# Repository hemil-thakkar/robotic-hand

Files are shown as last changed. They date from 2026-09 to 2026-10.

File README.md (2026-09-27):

# robotic-hand
# Tendon-driven robotic hand

Building a tendon-driven robotic hand as a step toward prosthetics and
wearable robotics research. Based on the open-source
[InMoov](https://inmoov.fr) hand, with my own modifications.

Biomedical engineering, Georgia Tech.

## Goals

- [ ] Print and assemble a single working finger
- [ ] Drive the finger with a servo and Arduino
- [ ] Build the full hand and forearm
- [ ] Design my own parts (mount, electrode holder, modified joint)
- [ ] Compare my finger design against the original for grip and range of motion
- [ ] Control the hand with an EMG (muscle) signal

## Status

**Stage 0 — first finger.** Repo set up. Next: print the InMoov finger
parts at the Georgia Tech Invention Studio, then assemble and string
the tendon.

See [`docs/build-log.md`](docs/build-log.md) for session notes.

## Repo layout

| Folder | Contents |
|---|---|
| `cad/` | My Fusion designs and exported STL files |
| `cad/reference/` | InMoov STL files as printed (not my designs) |
| `code/` | Arduino sketches and analysis scripts |
| `docs/` | Build log and test results |
| `docs/photos/` | Build photos, named by date |
| `data/` | Measurements from tests |

## Built with

- 3D printing at the Georgia Tech Invention Studio
- Autodesk Fusion for CAD
- Arduino for servo control

## Credit

Mechanical design based on the InMoov open-source humanoid robot by
Gael Langevin, licensed CC-BY-NC. Files in `cad/reference/` are his.
My own parts and code are in `cad/`, `code/`, and noted as mine in the
build log.

Mechanical design based on the InMoov open-source humanoid robot by
Gael Langevin, licensed CC-BY-NC. Files in `cad/reference/` are his.
My own parts and code are in `cad/`, `code/`, and noted as mine in the
build log.

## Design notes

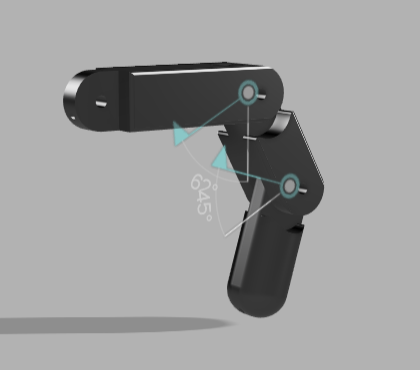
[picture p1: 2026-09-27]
photos/fusion-render-v1-finger.png

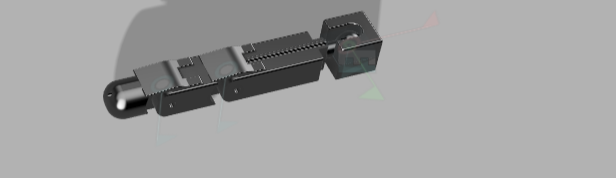
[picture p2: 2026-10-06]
photos/full-finger-v2.png

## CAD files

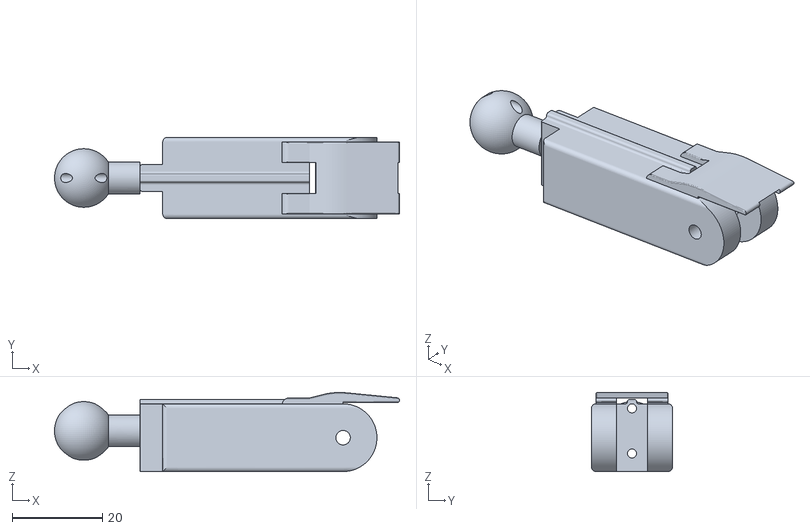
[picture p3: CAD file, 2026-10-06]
cad/personal cads/sweeps version/segment-proximal-ball-v1.stl
76.5 x 18.0 x 17.5

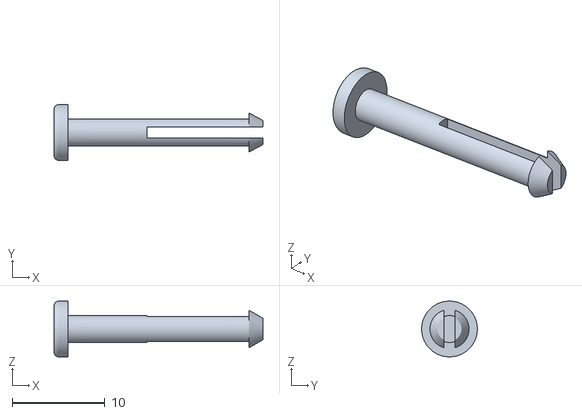
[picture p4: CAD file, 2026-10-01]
cad/personal cads/v1 (9-27-26)/connection-pin-v1.stl
22.5 x 6.00 x 6.00

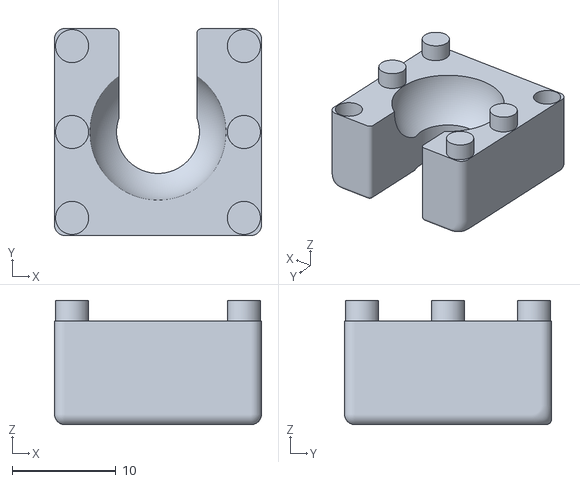
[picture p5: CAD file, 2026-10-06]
cad/personal cads/v2 (10-6-26)/socket-cap-v2.stl
20.0 x 20.0 x 12.0

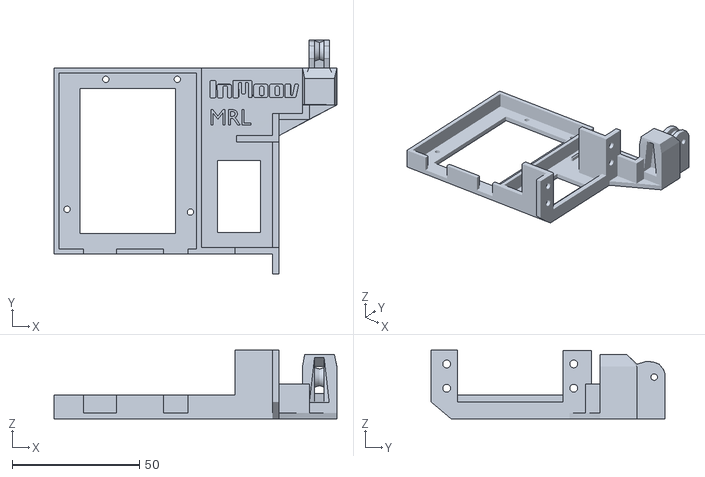
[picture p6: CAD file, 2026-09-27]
cad/reference/FingerTesterV2.stl
111.0 x 91.8 x 26.9

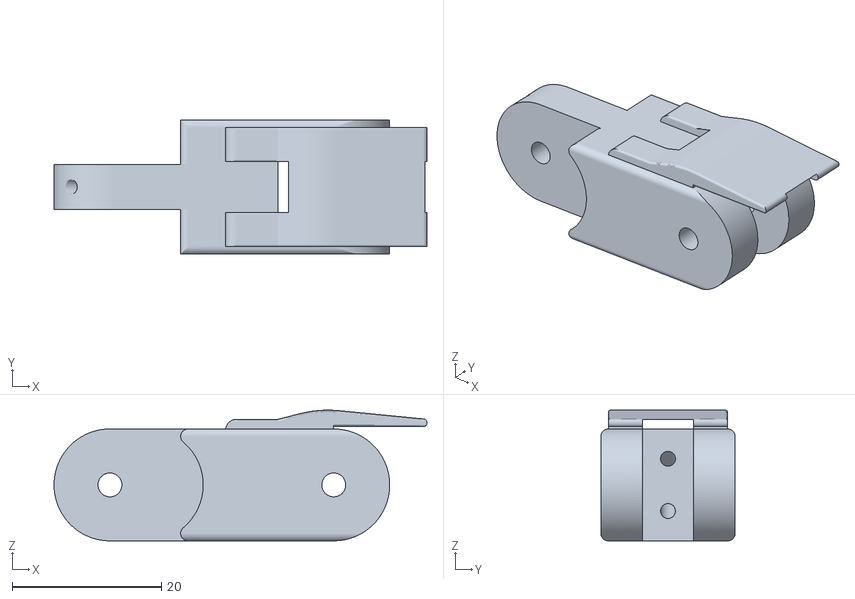
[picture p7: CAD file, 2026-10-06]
cad/personal cads/sweeps version/segment-middle-vSweep.stl
50.0 x 18.0 x 17.5

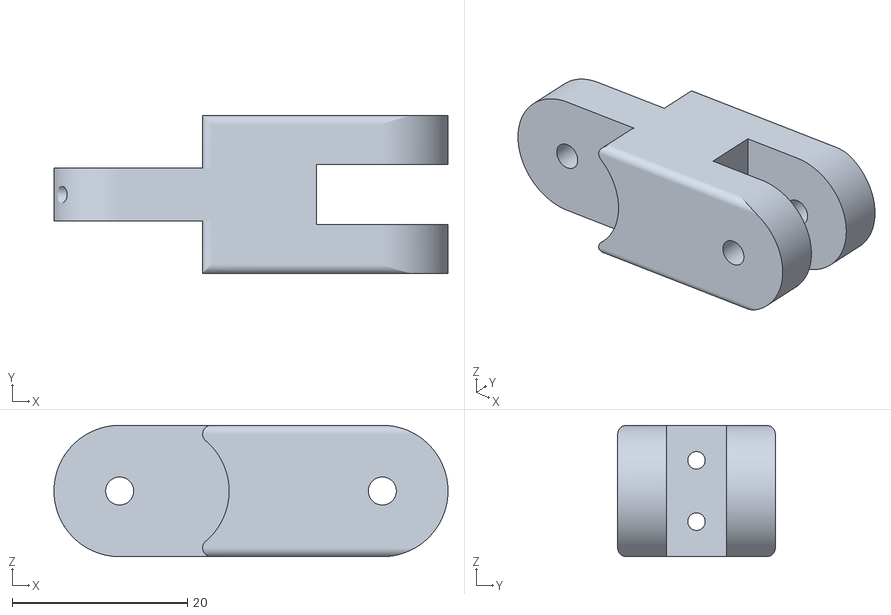
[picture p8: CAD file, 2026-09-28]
cad/personal cads/v1 (9-27-26)/segment-middle-v1.stl
45.0 x 18.0 x 15.0

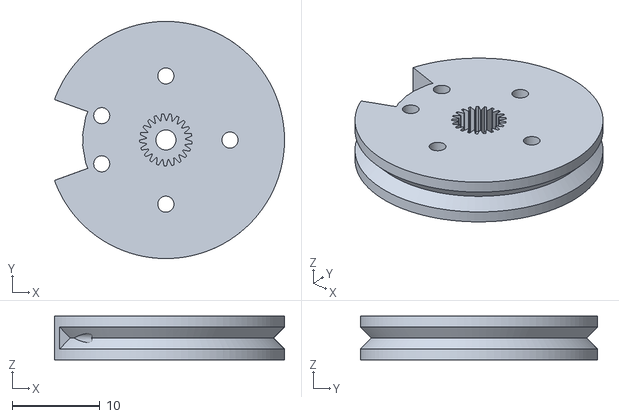
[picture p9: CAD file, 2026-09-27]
cad/reference/RobRingV2.stl
26.2 x 27.0 x 5.00

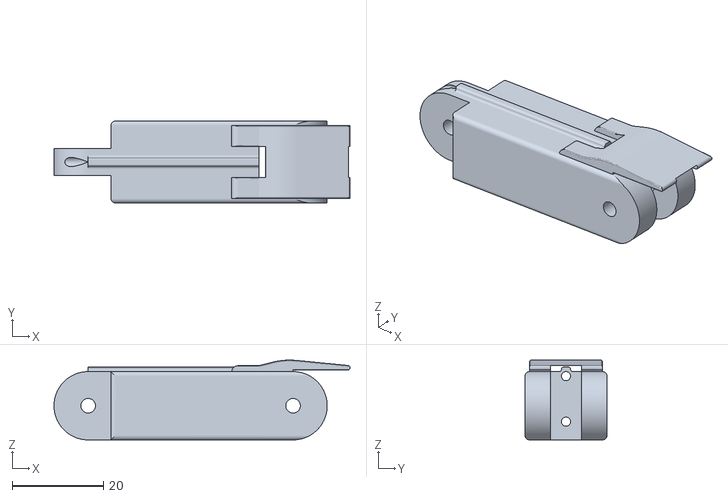
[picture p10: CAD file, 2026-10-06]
cad/personal cads/sweeps version/segment-proximal-v2 (extra hole space).stl
65.0 x 18.0 x 17.5

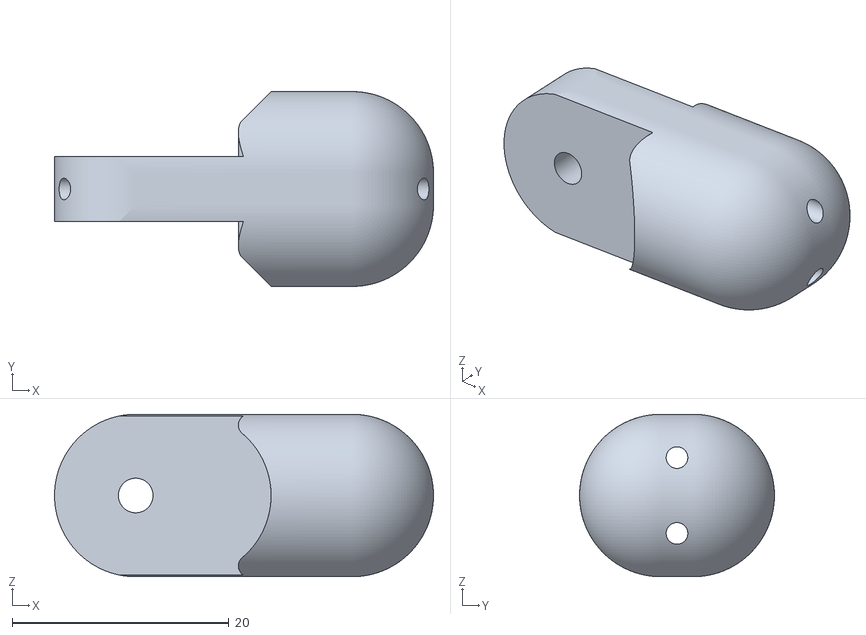
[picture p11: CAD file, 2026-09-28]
cad/personal cads/v1 (9-27-26)/segment-distal-v1.stl
35.0 x 18.0 x 15.0

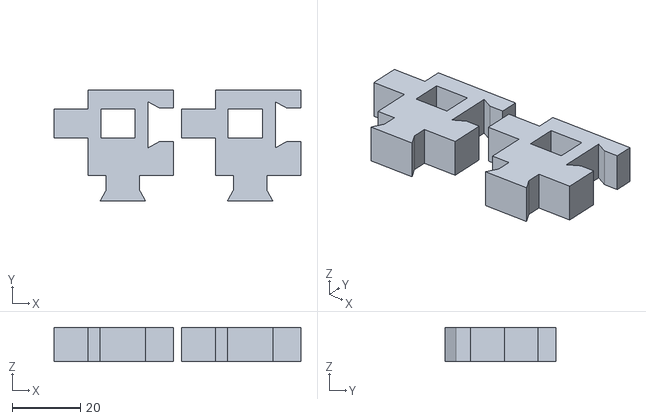
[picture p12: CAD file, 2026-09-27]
cad/reference/Calibrator.stl
72.2 x 32.5 x 9.99

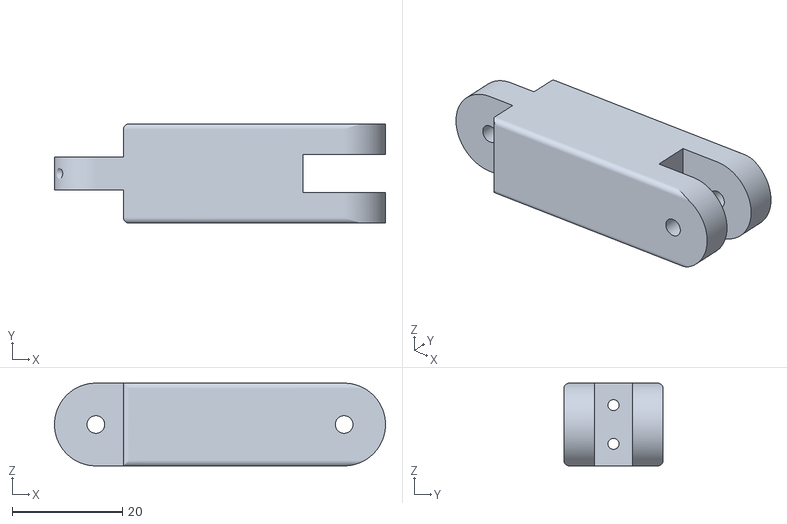
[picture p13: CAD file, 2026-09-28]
cad/personal cads/v1 (9-27-26)/segment-proximal-v1.stl
60.0 x 18.0 x 15.0

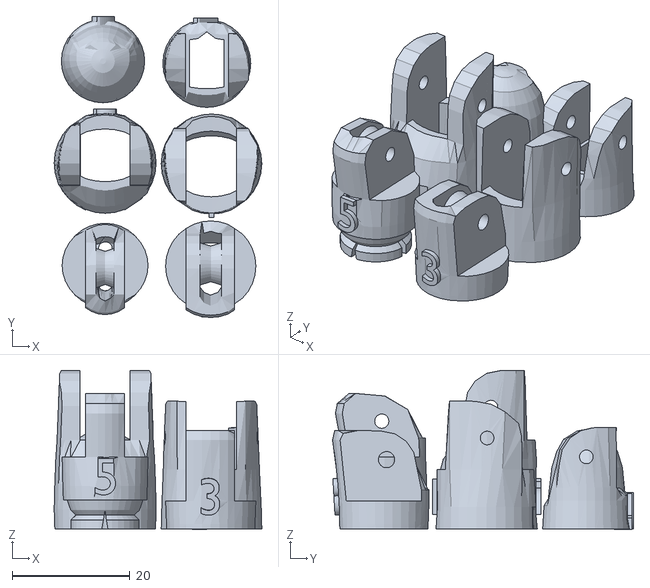
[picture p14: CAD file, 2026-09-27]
cad/reference/FingerIndexV4.stl
35.3 x 51.2 x 27.1

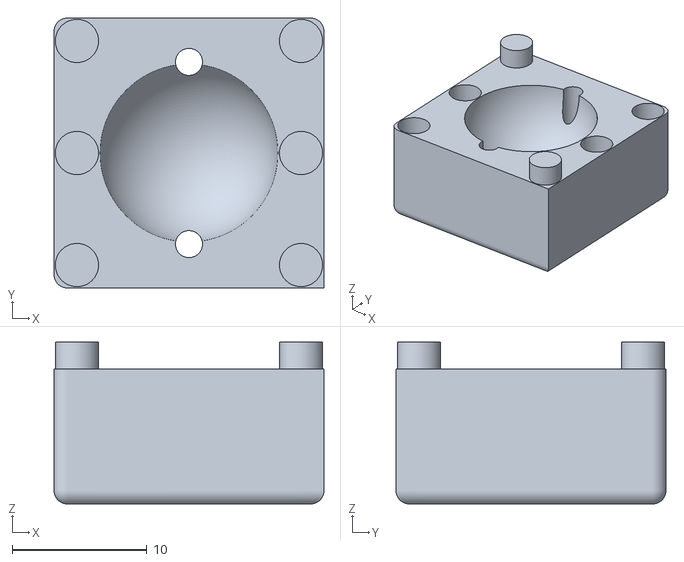
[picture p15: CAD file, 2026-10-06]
cad/personal cads/v2 (10-6-26)/socket-base-v2.stl
20.0 x 20.0 x 12.0

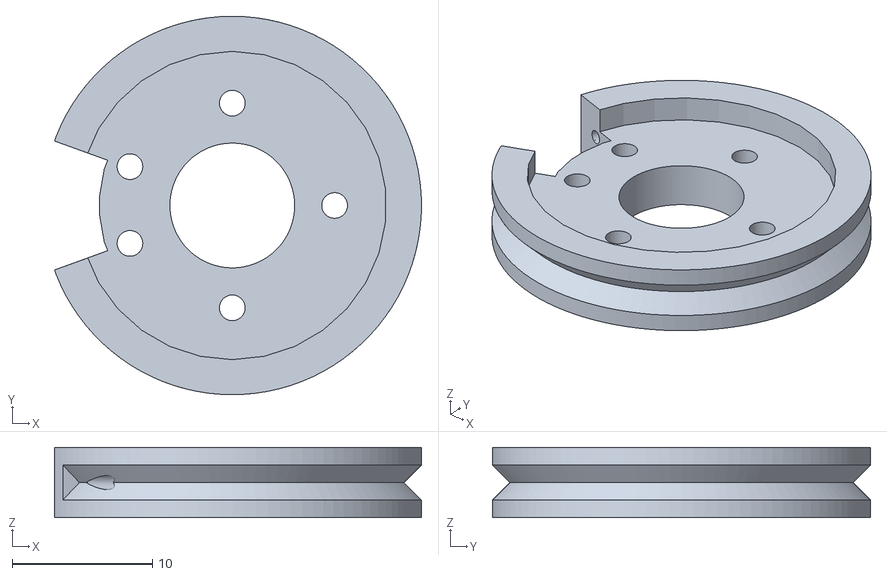
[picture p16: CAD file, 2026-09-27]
cad/reference/Servo-PulleyV2.stl
26.2 x 27.0 x 5.00

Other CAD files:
cad/personal cads/v2 (10-6-26)/segment-distal-v2.stl
cad/personal cads/v2 (10-6-26)/connection-pin-v2.stl

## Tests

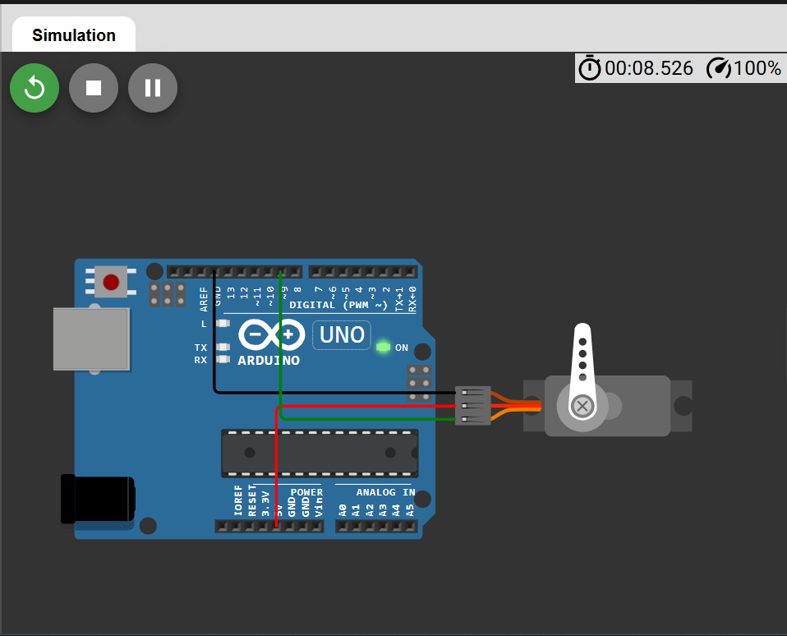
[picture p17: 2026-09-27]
photos/robotic-hand-servo-test.png

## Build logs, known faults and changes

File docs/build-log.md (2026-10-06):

# Build log

Newest entries at the top. For each session, note what you did, what
went wrong, and what you'd change. The failures are the useful part —
they're what you'll talk about in an interview.

---

## 2026-09-27 — Session 1: first servo test

**Goal:** The goal was to just test sample code for a servo on wokwi.com

**What I did:** Added code from Claude to the Arduino UNO simulation, added servo into the simulation and its libraries

**What went wrong:** Initially forgot to add libraries to simulation

**What I learned:** Do not forget to add necessary libraries

**Next step:** Continue to CAD and learn more about Arduino

**Photos:** [robotic-hand/photos/robotic-hand-servo-test](url)

---
## 2026-09-27 — Session 1: designed three finger segments in Fusion

**Goal:** Learn CAD by designing a tendon-driven finger from scratch
before looking at how InMoov solved it.

**What I did:** Modeled three segments (proximal, middle, distal) as
separate components in one Fusion file. Each has a fork at one end, a
tongue at the other, pivot holes through both, and a 2 mm tendon
channel running the full length below the pivots. Distal segment has
no fork and gets a counterbore at the tip so the tendon knot sits
recessed. Assembled with revolute joints and set joint limits.
Exported STLs.

**What went wrong:**

1. The 3-point arc bulged 7.5 mm past the rectangle, making the part
   47.5 mm instead of 40. Fixed by shortening the rectangle to 32.5 so
   rectangle + arc = intended length.

2. Adding a fillet to the tongue tip broke the pivot hole, because the
   circle was under-constrained and moved when the geometry changed.
   Fixed by making the hole's center coincident with the fillet arc's
   center — which is also the correct design, since the pivot should
   sit at the center of rotation.

3. Copying the segment and shortening it made the fork disappear
   entirely. The fork sketch was drawn at fixed coordinates that
   covered the rounded end at 40 mm, but landed off the part at 25 mm.

4. On the shorter segment, the fork and tongue nearly collided. Feature
   sizes that fit a 40 mm segment don't fit a 25 mm one.

**What I learned:**

- Geometry dimensioned from fixed coordinates doesn't move when the
  part changes; geometry constrained to projected features does.
  Rebuilt the sketches using Project so the fork and holes reference
  the arc instead of the origin.
- Fully constrained sketches (black geometry, padlock in browser)
  aren't cosmetic — they're what makes a design survive edits.
- Feature dimensions need to scale with the part, not stay fixed.
  A parameter like tongueLen = segLength * 0.25 would handle this.
- Fusion's new intent-driven design dialog: Hybrid mode is the
  classic everything-in-one-file workflow.
- Printer nozzles are 0.4 mm, so the minimum reliable feature is
  about 0.8–1 mm. Nothing in this design is close to that.

**Design decisions:**

- Segment lengths: 40 / 25 / 20 mm, adult index finger
- Cross section: 18 mm wide × 15 mm thick
- Tongue 6 mm thick into a 6.4 mm fork slot (0.2 mm clearance per side
  — may need widening once printed)
- 3.2 mm pivot holes for M3 bolts with nyloc nuts
- 7.5 mm tongue tip fillet = true half-round, centered on the pivot

**Next step:** Print one segment at the Invention Studio to check fit
and tolerances before printing all three. Source 2× M3 bolts and nyloc
nuts (~22–25 mm long) from Robo 101, WEAR, or the Hive.

**Photos:** [photos/robotic-hand-servo-test.png](url)

## 2026-09-30 — Session 2: first prints, pin failure, v2 redesign

**Goal:** Print the three finger segments and the snap-fit pivot pins,
assemble the finger, and check fit and range of motion.

**What I did:**

- Printed all three segments in PLA at the Invention Studio (FDM,
  Bambu Lab X1E), oriented on a side face so the pivot holes printed as
  vertical circles with no supports.
- Printed the connection pins in PETG. Removed supports and brim with
  flush cutters, filed the tongue and fork faces flush.
- Assembled the finger with pin fragments, confirmed both joints rotate
  ~90 degrees in each direction.
- Redesigned the pin as a two-part lap joint (v2) and widened nothing
  else.
- Added a knuckle shell over the joints and a tapered lip that acts as
  a hyperextension stop.

**What went wrong:**

1. **PETG pins came out stringy**, specifically on the slotted barb at
   the tip. Printing them vertically did not help. The barb halves were
   0.72 mm thick with a slot between them — too fine a feature for FDM
   in a material that strings as much as PETG.

2. **The pins snapped during insertion** and would not have fitted even
   if the barb had compressed cleanly. The barb was Ø4.05 going into a
   3.2 mm hole, so each half had to deflect ~0.43 mm over an 11 mm
   cantilever, in a brittle printed part.

3. **Discovered the fix by accident:** after the pins broke in half, the
   plain shaft fragments fitted the holes perfectly. Pushed one fragment
   into each side of a joint and the finger assembled and moved well.
   The barb was the fragile part and it turned out to be unnecessary.

**What I learned:**

- Feature size has to be matched to the process, not just to the design
  intent. A snap fit asks a brittle material to flex, which is the one
  thing it is bad at.
- Material choice drives stringing far more than print orientation does.
- A simpler mechanism that cannot fail beats a clever one that can. The
  two-stub pin has no flexing feature at all.
- Choosing a different manufacturing process per part (SLA for fine
  features, FDM for the bulk parts) is a legitimate design decision.

**v2 changes:**

- **Pin:** two-part lap joint. Head Ø6 x 1.5, shaft Ø2.88 x 11 mm,
  with the last ~4.2 mm cut down to a 1.28 mm flat so two pins overlap
  inside the tongue. Mated thickness 2.56 mm inside a 2.88 mm envelope.
  Combined reach 17.8 mm across a 17 mm joint stack, leaving ~0.8 mm
  axial play. No slot, no barb, nothing to snap.
- **Segments:** knuckle shell added over the joints; tapered lip added
  as a hyperextension stop so the finger stops at straight.

**Tendon routing decided:**

- Flexor runs through the bottom channel of all three segments, anchored
  at the tip. Extensor runs through the top channel of all three.
- The direction a tendon turns a joint depends on which side of the
  pivot it passes. Below the pivot closes the joint, above it opens it.
  A line through the pivot centre produces no torque at all.
- Flexion limited to ~90 degrees. Beyond that the tendon line crosses
  the pivot axis and pulling would start to extend the joint instead
  (over-centre).
- Planned: connect the two channels with a cross-hole near the distal
  tip so one continuous loop serves as both flexor and extensor, with
  no knot to slip.

**Open questions:**

- Whether the tendon channels should move further from the pivot
  (4 mm -> 2.5 mm from the bottom face) for a larger moment arm.
- Whether a single flexor will curl the fingertip before the base joint
  closes, which would shrink the grip aperture.
- Whether the lap pins migrate outward in use. Fallback is a dab of glue
  in the fork prong holes only, leaving the tongue free to rotate.

**Next step:** reprint segments and 8 lap pins. Thread a tendon and
confirm flexion direction by hand before motorising.

**Photos:** docs/photos/

## 2026-10-06 — Session 3: tendon routing tests and v2 redesign

**Goal:** Work out why the tendons produced so little flexion, then
redesign the finger around what the tests showed.

### Tendon routing experiments

Strung the printed v1 finger with dental floss, knotted at the tip, and
pulled by hand.

- **Both tendons strung conventionally (flexor bottom, extensor top):**
  very little flexion, roughly 25-30 degrees per joint, and it would not
  go further no matter how much string was pulled through.
- **Routed top-bottom-bottom instead:** significantly more range of
  motion from the same pull.

**What that means:** the limit was never string travel, it was torque.
The crossing route makes the string wrap around the rounded tongue tip
instead of taking a short chord between two channel exits. The tip is a
7.5 mm half-round centred on the pivot, so the wrapped string gets a
7.5 mm moment arm instead of 3.5 mm — more than double the torque for
the same pull.

This is also roughly how real flexor tendons work: they ride over the
joint, held against it by fibrous pulleys, rather than running straight
through the bone.

Several things had to be ruled out first — the base not being anchored,
knots pulling into the channels, friction at square channel exits, and
the joint simply running out of mechanical travel. Isolating one joint
at a time was what made the result readable.

### v2 changes

- **Knuckles** added to the proximal and middle segments to restrict
  hyperextension.
- **Proximal segment** now ends in a ball joint with tendon channels
  through the ball, giving rotation beyond simple flexion/extension
  plus a few degrees of side-to-side wiggle. Channel positions moved
  further from the pivot for a larger moment arm.
- **Middle segment:** channels moved further from the pivot, and the
  paths swept in a cross shape so the same top-to-bottom crossing that
  happens between proximal and middle also happens between middle and
  distal.
- **Distal segment:** channels moved further from the pivot to maximise
  flexion.
- **Connection pins:** replaced the snap-fit barb with two interlocking
  halves (lap joint). The v1 barb was 0.72 mm thick with a slot through
  it, which came out stringy in PETG and snapped on insertion. The v2
  pin has no flexing feature at all — head Ø6 x 1.5, shaft Ø2.88 x 11,
  with the last 4.2 mm cut to a 1.28 mm flat so two pins overlap inside
  the tongue.
- **Socket** designed for the proximal ball joint, with tendon channels
  in the base to carry the tendons from finger to hand. The mouth is a
  slot on one side only: open in the flexion direction (~14 mm, giving
  ~90 degrees), narrow across (8 mm, giving ~6-8 degrees of side-to-side),
  and closed on the other side to prevent hyperextension at this joint.

### Bugs caught by STL analysis

Two defects showed in the exported meshes but not in the CAD, both the
same cause: the ball and neck were modelled as separate bodies that
overlapped the segment rather than being joined to it. Overlapping
bodies render as one solid on screen, so nothing looked wrong, but the
mesh wrote an inside-out shell where they intersected — reported as a
second body with negative volume, plus a phantom void through the centre
of the ball. Fixed with Modify > Combine > Join. The void's diameter
matched the neck's exactly, which is what identified it.

**Lesson:** check body count in the exported mesh, not just the
on-screen model.

### Open questions

- Whether the crossing channel sweep reproduces the wrap effect, or
  whether a dedicated groove around the tongue tip would be better.
- Whether a single flexor tendon curls the fingertip before the base
  joint closes, shrinking the grip aperture.
- Whether the cap screws are strong enough to retain the ball under
  load, since the base bowl is cut at the equator and provides no
  retention on its own.

**Next:** print all six parts (3 segments, 8 lap pins, socket base,
socket cap), assemble, and test the full finger with poly tennis string
and an elastic return before adding a servo.

### Template to copy for each session

```
## YYYY-MM-DD — Session N: title

**Goal:**
**What I did:**
**What went wrong:**
**What I learned:**
**Next step:**
```

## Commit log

2026-09-27 Revise README for clarity on project status and credits
    Updated README to clarify project stages and credit.
2026-09-27 arduino code for a servo
    added test code for an arduino servo, tested on wokwi
2026-09-27 wokwi test folder for servo
    added wokwi test folder for servo
2026-09-27 Update build log for servo test session
2026-09-27 first personal cad finger
    created finger with connected joints and ability for each joint to flex in 90 degrees, 3 segments (proximal, middle, distal) with one hole through the whole finger for a tendon model to go through
    [segment-distal-v1.stl, segment-middle-v1.stl, segment-proximal-v1.stl]
2026-09-28 updates to first cad finger
    [segment-distal-v1.stl, segment-middle-v1.stl, segment-proximal-v1.stl]
2026-09-29 creation of connection pin at joints of each segment
    created a pin that compresses into the hole between the joints and snaps in to allow for clean rotation of the joints, print in PETG (polyethylene terephthalate with glycol), if no petg than do PLA
    [connection-pin-v1.stl]
2026-10-01 version 2 updates after first pring
    connection pin redesign to thicker prints so no stringiness, knucles added to segments to prevent hyperextension of joints
    [connection-pin-v1.stl, connection-pin-v2.stl, segment-distal-v2.stl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]
2026-10-01 Document Session 2 findings and design changes
    Added details for Session 2, including goals, actions taken, issues encountered, lessons learned, v2 changes, tendon routing decisions, open questions, and next steps.
2026-10-06 v2 ready to print
    - knuckles on proximal and middle segment to add restriction on hyper extension of fingers
    - proximal segment now has ball joint with tendon channels to allow for rotation beyond just up n down, gives slight wiggle room, more extreme hole distances for greater rom to rotate the middle segm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
    - middle segment has more extreme holes to allow for more rotation when tendons are pulled, sweeps that go in a cross shape to allow for the same top-bottom connection the occurs between proximal and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
    - distal segment has more extreme holes to add rom and maximize flexion of the segment
    - connection pins changed to be two halves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
    [connection-pin-v2.stl, segment-distal-v2.stl, segment-middle-v2.stl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]
2026-10-06 Add session 3 details on tendon routing and redesign
    Documented tendon routing tests and v2 redesign changes, including new features and bugs identified during STL analysis.
2026-10-19 Add palm v2 and v5 knuckle joint: build log sessions 4-5, CAD files, photos
